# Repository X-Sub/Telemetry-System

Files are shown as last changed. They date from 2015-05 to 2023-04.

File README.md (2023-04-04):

# X-Sub Telemetry System
X-Sub Telemetry System is a project developed by the Mechatronics Research and Development Group (MRDG) at the Simon Bolivar University. The project aims to create a telemetry system for remote teleoperation of underwater robots and related technologies for research, exploration, and underwater inspection.

## Getting Started
To get started with this project, you need to fork your own copy of X-Sub/Telemetry-System. After forking, you can clone the project to your local machine and start working on it.

## Project Structure
The project is divided into different branches, and each branch contains code related to a specific module of the project. The branches include:

* LabView Visualizer
* MCU Firmware
* PCB
* Python Data Receiver-Transmitter
* Spectrum Analyzer

Additionally, there are other files included in the project such as a readme, gitignore, and gitattributes files.

## Usage
The X-Sub Telemetry System is designed to provide remote teleoperation of underwater robots. It consists of a 32-bit microcontroller that acquires sensor signals and centralizes them to a PC board. The PC board keeps a record of all data and forwards them to a base station, which commands for control motors and other actuators on board are received.

## Contributing
Contributions to this project are welcome. If you find any issues or want to make any improvements, you can create an issue or submit a pull request.

## License
This project is licensed under the MIT License - see the LICENSE.md file for details.

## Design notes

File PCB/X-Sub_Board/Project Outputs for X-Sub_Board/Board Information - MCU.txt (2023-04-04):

Board Information Report
Filename     : C:\Users\ddtdanilo\Dropbox\Tesis\X-Sub\PCB\X-Sub_Board\MCU.PcbDoc
Date         : 02/11/2015
Time         : 9:50:49
Time Elapsed : 00:00:00

General
    Board Size, 3664.37milsx2121.064mils
    Components on board, 36
count : 2

Routing Information
    Routing completion, 70,09%
    Connections, 107
    Connections routed, 75
    Connections remaining, 32
count : 4

Layer, Arcs, Pads, Vias, Tracks, Texts, Fills, Regions, ComponentBodies
    Top Layer, 0, 99, 0, 392, 0, 0, 0, 0
    Bottom Layer, 0, 0, 0, 141, 3, 0, 0, 0
    Mechanical 1, 0, 0, 0, 0, 0, 0, 0, 0
    Mechanical 2, 0, 0, 0, 0, 0, 0, 0, 0
    Mechanical 4, 0, 0, 0, 0, 0, 0, 0, 0
    Mechanical 13, 1, 0, 0, 64, 0, 0, 0, 16
    Mechanical 15, 0, 0, 0, 96, 0, 0, 0, 0
    Mechanical 16, 0, 0, 0, 50, 4, 0, 0, 0
    Multi-Layer, 0, 113, 14, 0, 0, 0, 1, 0
    Top Paste, 0, 0, 0, 0, 0, 0, 0, 0
    Top Overlay, 12, 0, 0, 132, 76, 1, 0, 0
    Top Solder, 0, 0, 0, 0, 0, 0, 0, 0
    Bottom Solder, 0, 0, 0, 0, 0, 0, 0, 0
    Bottom Overlay, 1, 0, 0, 4, 2, 0, 0, 0
    Bottom Paste, 0, 0, 0, 0, 0, 0, 0, 0
    Drill Guide, 0, 0, 0, 0, 0, 0, 0, 0
    Keep-Out Layer, 0, 0, 0, 0, 0, 0, 0, 0
    Drill Drawing, 0, 0, 0, 0, 0, 0, 0, 0
count : 18

Layer Pairs, Vias
    Top Layer - Bottom Layer, 14
count : 1

Non-Plated Hole Size, Pads, Vias
count : 0

Plated Hole Size, Pads, Vias
    0mils, 99, 0
    25mils, 0, 14
    35mils, 104, 0
    102.362mils, 2, 0
    126mils, 4, 0
    149.606mils, 3, 0
count : 6

Non-Plated Slot Size / Length, Pads
count : 0

Plated Slot Size / Length, Pads
count : 0

Non-Plated Square Hole Size, Pads
count : 0

Plated Square Hole Size, Pads
count : 0

Top Layer Annular Ring Size, Count
    -89.606mils, 3
    -42.362mils, 2
    0mils, 4
    25mils, 14
    35mils, 104
count : 5

Mid Layer Annular Ring Size, Count
    -89.606mils, 3
    -42.362mils, 2
    0mils, 4
    25mils, 14
    35mils, 104
count : 5

Bottom Layer Annular Ring Size, Count
    -89.606mils, 3
    -42.362mils, 2
    0mils, 4
    25mils, 14
    35mils, 104
count : 5

Pad Solder Mask, Count
    4mils, 212
count : 1

Pad Paste Mask, Count
    0mils, 212
count : 1

Pad Pwr/Gnd Expansion, Count
    20mils, 212
count : 1

Pad Relief Conductor Width, Count
    10mils, 212
count : 1

Pad Relief Air Gap, Count
    10mils, 212
count : 1

Pad Relief Entries, Count
    2, 212
count : 1

Via Solder Mask, Count
    4mils, 14
count : 1

Via Pwr/Gnd Expansion, Count
    20mils, 14
count : 1

Track Width, Count
    1.969mils, 8
    3.937mils, 152
    5mils, 16
    7.874mils, 122
    8mils, 15
    10mils, 72
    12mils, 356
    19.685mils, 97
    39.37mils, 41
count : 9

Arc Line Width, Count
    3.937mils, 1
    7.874mils, 8
    9.843mils, 4
    23.622mils, 1
count : 4

Arc Radius, Count
    4.921mils, 4
    11.811mils, 1
    19.685mils, 1
    78.74mils, 8
count : 4

Arc Degrees, Count
    122, 8
    360, 6
count : 2

Text Height, Count
    17mils, 2
    19.685mils, 4
    31mils, 2
    39.37mils, 52
    60mils, 20
    78.74mils, 1
    118.11mils, 4
count : 7

Text Width, Count
    2.55mils, 2
    8mils, 4
    10mils, 79
count : 3

Net Track Width, Count
    77780.886mils, 37
count : 1

Net Via Size, Count
    50mils, 37
count : 1

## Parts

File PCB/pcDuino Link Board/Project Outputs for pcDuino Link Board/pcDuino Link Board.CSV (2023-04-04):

Bill of Material for
On 30/09/2015 at 8:26:46
Comment | Pattern | Quantity | Components
Cap Pol1 | CAPR5-4X5 | 2 | C_5V, C_12V | Polarized Capacitor (Radial)
Header 10 | HDR1X10 | 1 | pcDuino Digital (8-13) | Header, 10-Pin
Header 2H | HDR1X2H | 1 | 5V_Sel | Header, 2-Pin, Right Angle
Header 2X2 | HDR2X2 | 2 | GPIO2, GPIO2_OUT | Header, 2-Pin, Dual row
Header 3 | HDR1X3 | 1 | Serial1 | Header, 3-Pin
Header 3X2 | HDR2X3 | 2 | GPIO1, ICSP | Header, 3-Pin, Dual row
Header 6 | HDR1X6 | 1 | pcDuinoADC | Header, 6-Pin
Header 8 | HDR1X8 | 2 | pcDuino Digital (0 - 7), pcDuino Power | Header, 8-Pin
LED1 | LED-1 | 3 | D_3.3, D_5, D_S | Typical RED GaAs LED
Res | RESC6332 | 3 | R_3.3, R_5, R_S | Resistor
Shield form compatible with the Arduino Uno R3. | UNO_R3_SHIELD | 1 | Duino Conn
Switching Power Source X-Sub | Fuente_Switching | 1 | PS
VCC_In | Vcc_In | 1 | Vin

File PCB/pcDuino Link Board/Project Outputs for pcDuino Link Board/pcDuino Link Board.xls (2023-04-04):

Comment | Description | Designator | Footprint | LibRef | Quantity
Header 2H | Header, 2-Pin, Right Angle | 5V_Sel | HDR1X2H | Header 2H | 1
Cap Pol1 | Polarized Capacitor (Radial) | C_5V, C_12V | CAPR5-4X5 | Cap Pol1 | 2
Shield form compatible with the Arduino Uno R3. |  | Duino Conn | UNO_R3_SHIELD | ARDUINO_R3_SHIELDNOLABELS | 1
LED1 | Typical RED GaAs LED | D_3.3, D_5, D_S | LED-1 | LED1 | 3
Header 3X2 | Header, 3-Pin, Dual row | GPIO1, ICSP | HDR2X3 | Header 3X2 | 2
Header 2X2 | Header, 2-Pin, Dual row | GPIO2, GPIO2_OUT | HDR2X2 | Header 2X2 | 2
Header 8 | Header, 8-Pin | pcDuino Digital (0 - 7), pcDuino Power | HDR1X8 | Header 8 | 2
Header 10 | Header, 10-Pin | pcDuino Digital (8-13) | HDR1X10 | Header 10 | 1
Header 6 | Header, 6-Pin | pcDuinoADC | HDR1X6 | Header 6 | 1
Switching Power Source X-Sub |  | PS | Fuente_Switching | Switching Power Source X-Sub | 1
Res | Resistor | R_3.3, R_5, R_S | RESC6332 | Res3 | 3
Header 3 | Header, 3-Pin | Serial1 | HDR1X3 | Header 3 | 1
VCC_In |  | Vin | Vcc_In | VCC_In | 1

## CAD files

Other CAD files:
MCU Firmware/test1/FLASH/Sources/main_c.obj
MCU Firmware/X-Sub MCU Firmware/FLASH/Sources/main_c.obj
MCU Firmware/test1/FLASH/Generated_Code/Cpu_c.obj
MCU Firmware/test1/FLASH/Project_Settings/Startup_Code/startcf_c.obj
MCU Firmware/test1/FLASH/Sources/Events_c.obj
MCU Firmware/X-Sub MCU Firmware/FLASH/Generated_Code/sMCU_OK_c.obj
MCU Firmware/X-Sub MCU Firmware/FLASH/Init_c.obj
MCU Firmware/X-Sub MCU Firmware/FLASH/Project_Settings/Startup_Code/startcf_c.obj
MCU Firmware/X-Sub MCU Firmware/FLASH/Sources/xSub_c.obj
MCU Firmware/test1/FLASH/Generated_Code/Vectors_c.obj
MCU Firmware/X-Sub MCU Firmware/FLASH/Generated_Code/RESET_INTERRUPT_c.obj
MCU Firmware/X-Sub MCU Firmware/FLASH/Sources/Events_c.obj
MCU Firmware/test1/FLASH/Generated_Code/IO_Map_c.obj
MCU Firmware/X-Sub MCU Firmware/FLASH/Generated_Code/M2_ESC_c.obj
MCU Firmware/X-Sub MCU Firmware/FLASH/Generated_Code/LedLight2_c.obj
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

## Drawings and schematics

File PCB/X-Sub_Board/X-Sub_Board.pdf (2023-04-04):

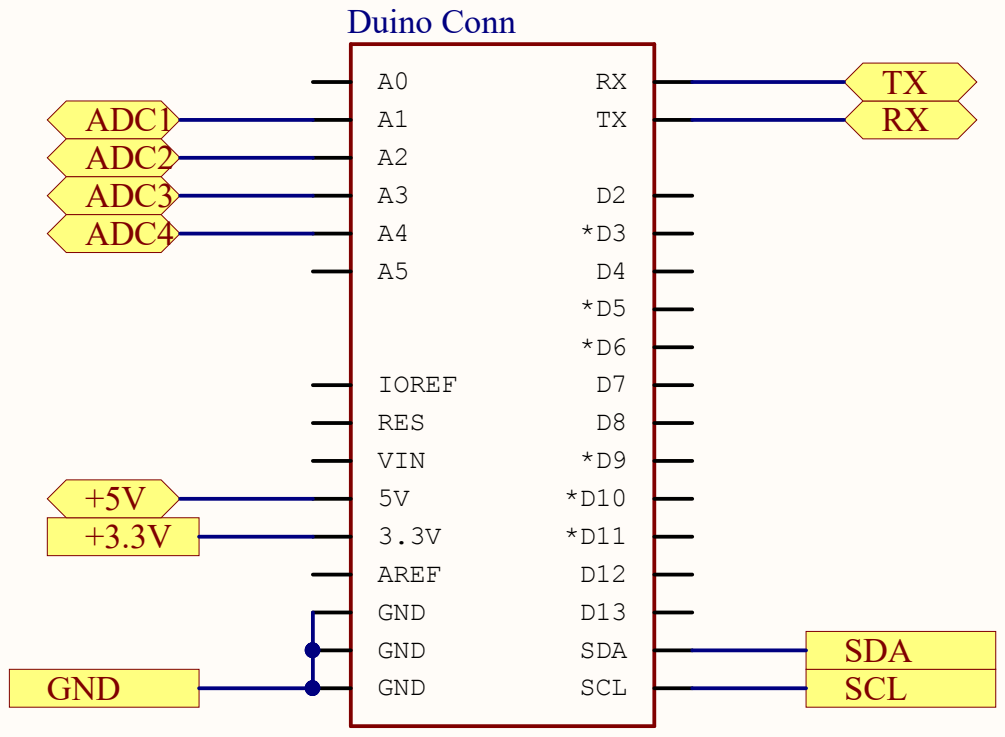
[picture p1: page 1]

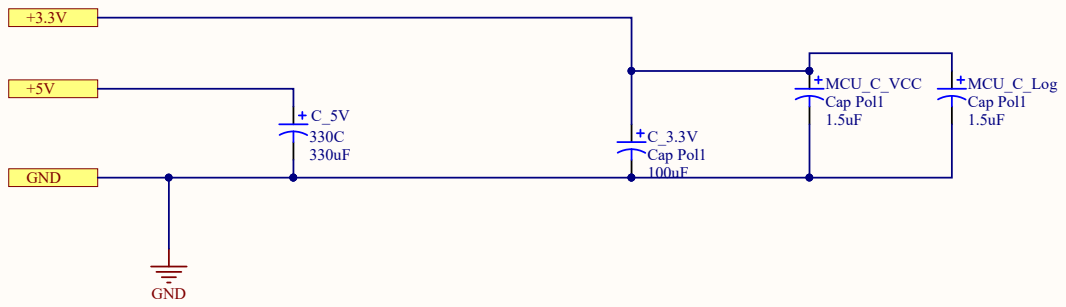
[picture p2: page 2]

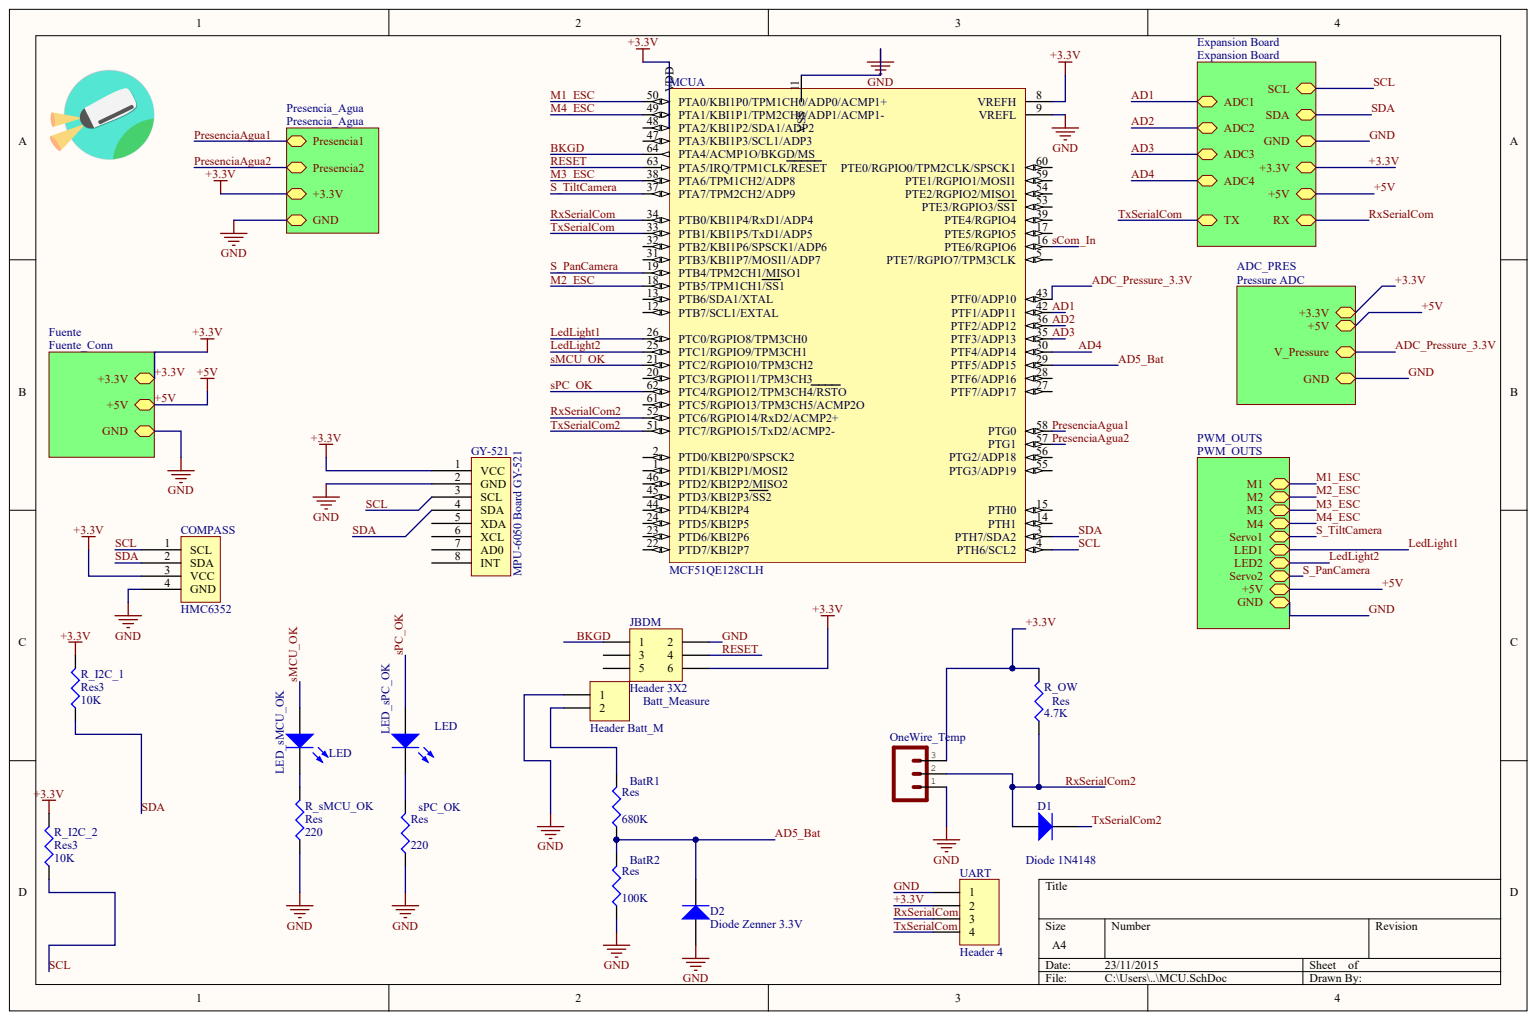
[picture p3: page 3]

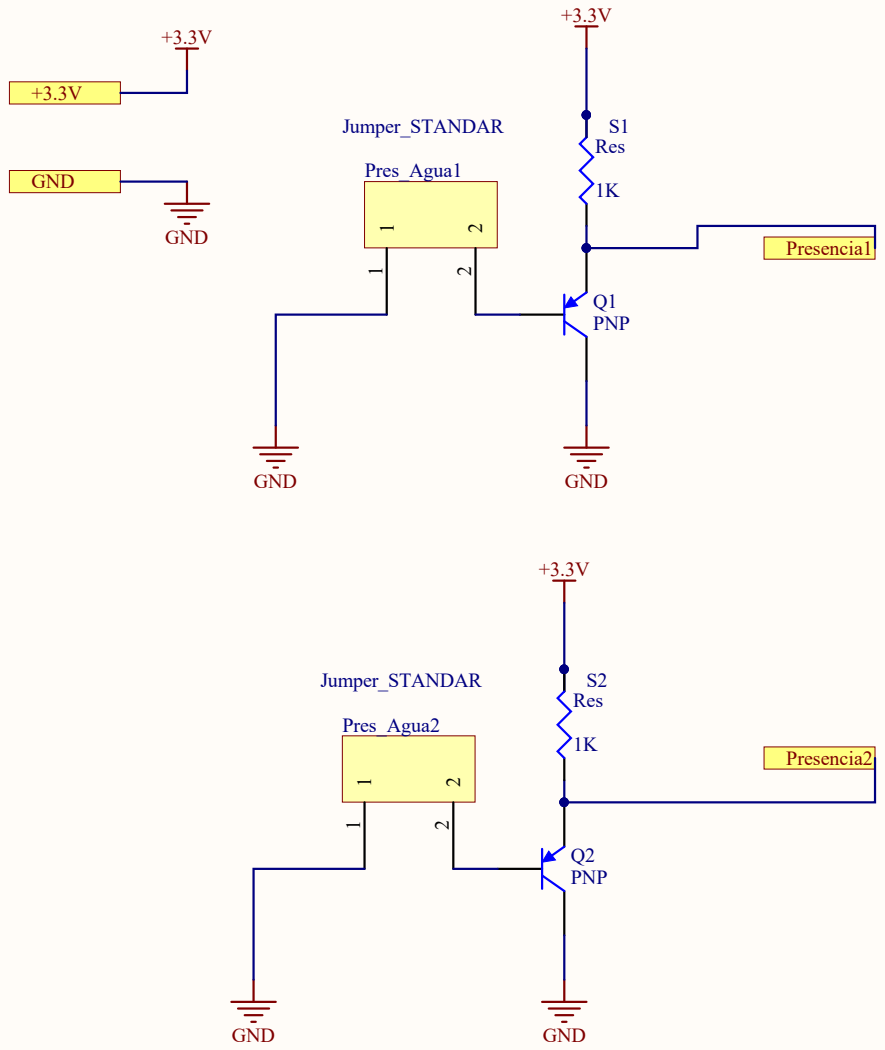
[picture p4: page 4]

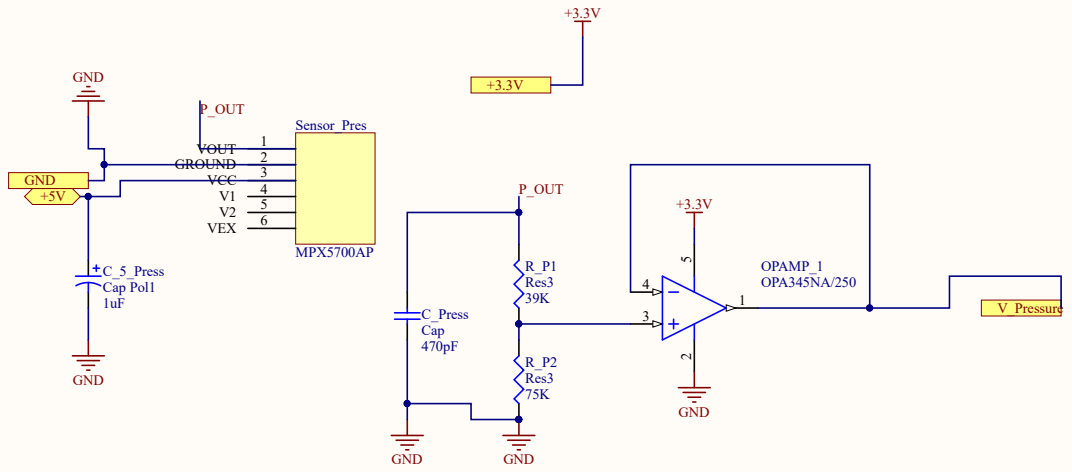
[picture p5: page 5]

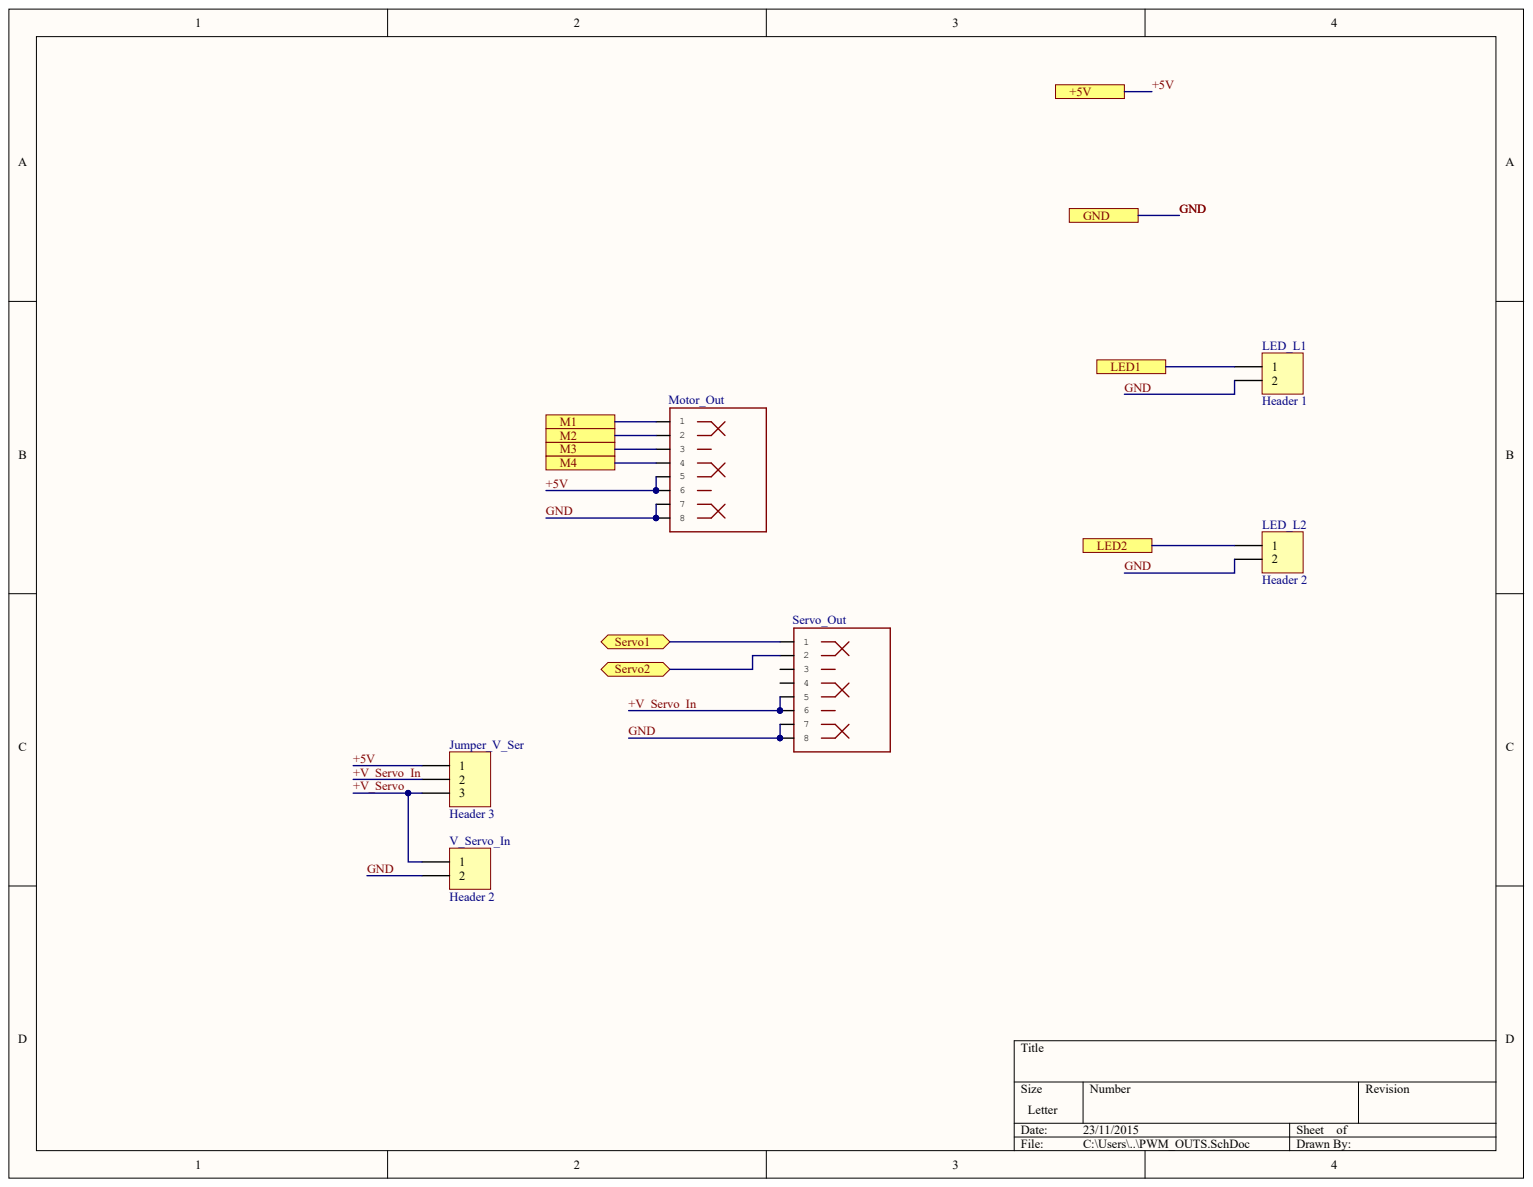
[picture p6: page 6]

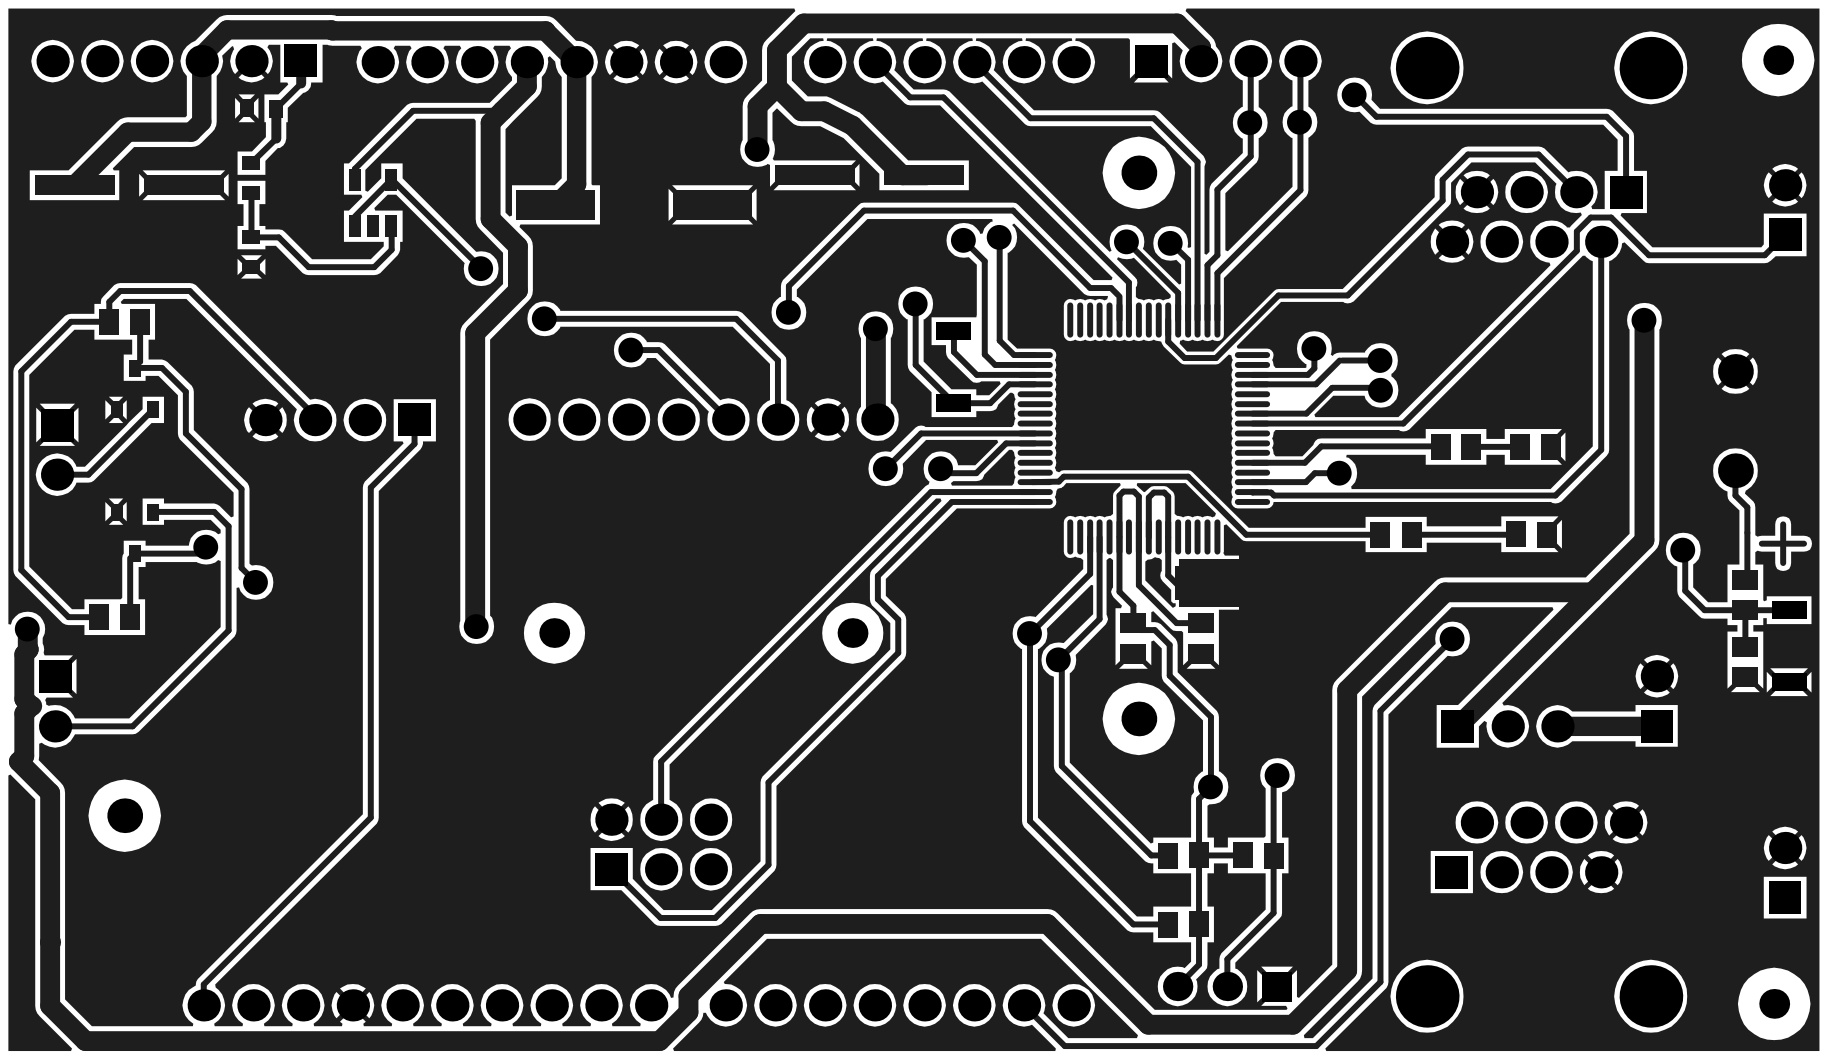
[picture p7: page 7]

# Board S

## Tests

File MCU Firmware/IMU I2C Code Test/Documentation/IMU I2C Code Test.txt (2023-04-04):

=============================================================================
List of generated methods in project: main

THIS TEXT DESCRIPTION IS GENERATED BY THE TOOL. DO NOT MODIFY IT.
=============================================================================

Module "CI2C1"     (component InternalI2C)
   - CI2C1_SendChar -When working as a MASTER, this method writes one (7-bit addressing) or two (10-bit addressing) slave 
                address bytes inclusive of R/W bit = 0 to the I2C bus and then writes one character (byte) to the bus. The 
                slave address must be specified before, by the "SelectSlave" or "SelectSlave10" method or in the component 
                initialization section, "Target slave address init" property. If interrupt service is enabled and the method 
                returns ERR_OK, it doesn't mean that transmission was successful. The state of transmission is obtainable from 
                (OnTransmitData, OnError or OnArbitLost) events.   When working as a SLAVE, this method writes a character to 
                the internal output slave buffer and, after the master starts the communication, to the I2C bus. If no 
                character is ready for a transmission (internal output slave buffer is empty), the Empty character will be sent 
                (see "Empty character" property).
   - CI2C1_RecvChar -When working as a MASTER, this method writes one (7-bit addressing) or two (10-bit addressing) slave 
                address bytes inclusive of R/W bit = 1 to the I2C bus, then reads one character (byte) from the bus and then 
                sends the stop condition. The slave address must be specified before, by the "SelectSlave" or "SelectSlave10" 
                method or in component initialization section, property "Target slave address init". If interrupt service is 
                enabled and the method returns ERR_OK, it doesn't mean that transmission was finished successfully. The state 
                of transmission must be tested by means of events (OnReceiveData, OnError or OnArbitLost). In case of 
                successful transmission, received data is ready after OnReceiveData event is called.   When working as a SLAVE, 
                this method reads a character from the input slave buffer.
   - CI2C1_SendBlock -When working as a MASTER, this method writes one (7-bit addressing) or two (10-bit addressing) slave 
                address bytes inclusive of R/W bit = 0 to the I2C bus and then writes the block of characters to the bus. The 
                slave address must be specified before, by the "SelectSlave" or "SlaveSelect10" method or in component 
                initialization section, "Target slave address init" property. If interrupt service is enabled and the method 
                returns ERR_OK, it doesn't mean that transmission was successful. The state of transmission is detectable by 
                means of events (OnTransmitData, OnError or OnArbitLost). Data to be send is not copied to an internal buffer 
                and remains in the original location. Therefore the content of the buffer should not be changed until the 
                transmission is complete. Event OnTransmitData can be used to detect the end of the transmission.  When working 
                as a SLAVE, this method writes a block of characters to the internal output slave buffer and then, after the 
                master starts the communication, to the I2C bus. If no character is ready for a transmission (internal output 
                slave buffer is empty), the "Empty character" will be sent (see "Empty character" property). In SLAVE mode the 
                data are copied to an internal buffer, if specified by "Output buffer size" property.
   - CI2C1_RecvBlock -When working as a MASTER, this method writes one (7-bit addressing) or two (10-bit addressing) slave 
                address bytes inclusive of R/W bit = 1 to the I2C bus, then reads the block of characters from the bus and then 
                sends the stop condition. The slave address must be specified before, by the "SelectSlave" or "SelectSlave10" 
                method or in component initialization section, "Target slave address init" property. If interrupt service is 
                enabled and the method returns ERR_OK, it doesn't mean that transmission was finished successfully. The state 
                of transmission must be tested by means of events (OnReceiveData, OnError or OnArbitLost). In case of 
                successful transmission, received data is ready after OnReceiveData event is called.   When working as a SLAVE, 
                this method reads a block of characters from the input slave buffer.
   - CI2C1_GetCharsInTxBuf -Returns number of characters in the output buffer. In SLAVE mode returns the number of characters 
                in the internal slave output buffer. In MASTER mode returns number of characters to be sent from the user 
                buffer (passed by SendBlock method).  This method is not supported in polling mode.
   - CI2C1_GetCharsInRxBuf -Returns number of characters in the input buffer. In SLAVE mode returns the number of characters in 
                the internal slave input buffer. In MASTER mode returns number of characters to be received into a user buffer 
                (passed by RecvChar or RecvBlock method).   This method is not supported in polling mode.
   - CI2C1_SelectSlave -This method selects a new slave for communication by its 7-bit slave address value. Any send or receive 
                method directs to or from selected device, until a new slave device is selected by this method. This method is 
                not available for the SLAVE mode.

Module "Cpu"       (component MCF51QE128_80)
   - Cpu_EnableInt -Enables maskable interrupts
   - Cpu_DisableInt -Disables maskable interrupts

===================================================================================

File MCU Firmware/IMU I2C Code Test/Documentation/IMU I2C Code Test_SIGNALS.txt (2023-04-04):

=================================================================
THIS FILE WAS GENERATED BY "Processor Expert version 10.3 for Freescale Microcontrollers".
Project "IMU I2C Code Test", 2015-07-17, 19:45, # CodeGen: 1
DO NOT MODIFY IT.
-----------------------------------------------------------------
There is no signal defined in this project.
 Hint: Signals may be defined in the Inspector (advanced or expert view)
=================================================================

=================================================================
 SIGNAL LIST
-----------------------------------------------------------------
SIGNAL-NAME [DIR]        => PIN-NAME [PIN-NUMBER]
-----------------------------------------------------------------
=================================================================

=================================================================
 PIN LIST
-----------------------------------------------------------------
PIN-NAME [PIN-NUM]       => SIGNAL-NAME [DIRECTION]
-----------------------------------------------------------------
=================================================================

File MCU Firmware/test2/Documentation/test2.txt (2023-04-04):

=============================================================================
List of generated methods in project: main

THIS TEXT DESCRIPTION IS GENERATED BY THE TOOL. DO NOT MODIFY IT.
=============================================================================

Module "UTIL1"     (component Utility)
   - UTIL1_strcpy -Same as normal strcpy, but safe as it does not write beyond the buffer.
   - UTIL1_strcat -Same as normal strcat, but safe as it does not write beyond the buffer.
   - UTIL1_chcat -Adds a single character to a zero byte terminated buffer. It cares about buffer overflow.
   - UTIL1_Num8sToStr -Converts a signed 8bit value into a string.
   - UTIL1_Num8uToStr -Converts an unsigned 8bit value into a string.
   - UTIL1_Num16sToStr -Converts a signed 16bit value into a string.
   - UTIL1_Num16uToStr -Converts a signed 16bit value into a string.
   - UTIL1_Num32uToStr -Converts an unsigned 32bit value into a string.
   - UTIL1_Num32sToStr -Converts a signed 32bit value into a string.
   - UTIL1_Num16sToStrFormatted -Converts a 16bit signed value to string.
   - UTIL1_Num16uToStrFormatted -Converts a 16bit unsigned value to string.
   - UTIL1_Num32uToStrFormatted -Converts a 32bit unsigned value to string.
   - UTIL1_Num32sToStrFormatted -Converts a 32bit signed value to string.
   - UTIL1_strcatNum8u -Appends a 8bit unsigned value to a string buffer.
   - UTIL1_strcatNum8s -Appends a 8bit signed value to a string buffer.
   - UTIL1_strcatNum16u -Appends a 16bit unsigned value to a string buffer.
   - UTIL1_strcatNum16s -Appends a 16bit signed value to a string buffer.
   - UTIL1_strcatNum32u -Appends a 32bit signed value to a string buffer.
   - UTIL1_strcatNum32s -Appends a 32bit signed value to a string buffer.
   - UTIL1_strcatNum16uFormatted -Appends a 16bit unsigned value to a string buffer in a formatted way.
   - UTIL1_strcatNum16sFormatted -Appends a 16bit signed value to a string buffer in a formatted way.
   - UTIL1_strcatNum32uFormatted -Appends a 32bit unsigned value to a string buffer in a formatted way.
   - UTIL1_strcatNum32sFormatted -Appends a 32bit signed value to a string buffer in a formatted way.
   - UTIL1_strcatNum8Hex -Appends a 8bit unsigned value to a buffer as hex number (without a 0x prefix).
   - UTIL1_strcatNum16Hex -Appends a 16bit unsigned value to a buffer as hex number (without a 0x prefix).
   - UTIL1_strcatNum24Hex -Appends a 32bit unsigned value to a buffer as hex number (without a 0x prefix). Only 24bits are used.
   - UTIL1_strcatNum32Hex -Appends a 16bit unsigned value to a buffer as hex number (without a 0x prefix).
   - UTIL1_strcatNum32sDotValue100 -Appends a 32bit signed value to a buffer. The value is in 1/100 units.  For example for the 
                value -13456 it will append the string "-134.56"
   - UTIL1_IsLeapYear -Returns true if a given year is a leap year
   - UTIL1_WeekDay -Returns the weekday for a given date >= 1.Jan.1900
   - UTIL1_ReadEscapedName -Scans an escaped name from a string. This is useful e.g. for double quoted file names.
   - UTIL1_xatoi -Custom atoi() (ascii to int) implementation by Elm Chan
   - UTIL1_ScanDate -Scans a date in the format "dd.mm.yyyy" or "dd-mm-yyyy". For yy it will expand it to 20yy.
   - UTIL1_ScanTime -Scans a time string in the format "hh:mm:ss,hh" with the part for the ",hh" is optional.
   - UTIL1_ScanDecimal8uNumber -Scans a decimal 8bit unsigned number
   - UTIL1_ScanDecimal8sNumber -Scans a decimal 8bit signed number
   - UTIL1_ScanDecimal16uNumber -Scans a decimal 16bit unsigned number
   - UTIL1_ScanDecimal16sNumber -Scans a decimal 16bit signed number
   - UTIL1_ScanDecimal32uNumber -Scans a decimal 32bit unsigned number
   - UTIL1_ScanDecimal32sNumber -Scans a decimal 32bit signed number
   - UTIL1_ScanDecimal32sDotNumber -Scans a decimal 32bit signed number with a following dot (fractional part), e.g. "-34587.
                0248", it will return the (signed) integral and fractional part with number of fractional zeros. The function 
                accepts as well numbers  like "17" (no fractional part" or "17.0"
   - UTIL1_ScanHex8uNumber -Scans a hexadecimal 8bit number, starting with 0x
   - UTIL1_ScanHex8uNumberNoPrefix -Scans a hexadecimal 8bit number, without 0x
   - UTIL1_ScanHex16uNumber -Scans a hexadecimal 16bit number, starting with 0x
   - UTIL1_ScanHex32uNumber -Scans a hexadecimal 32bit number, starting with 0x
   - UTIL1_ScanSeparatedNumbers -Scans multiple numbers separated by character, e.g. "123.68.5.3"
   - UTIL1_ScanDoubleQuotedString -Scans a string inside double quotes and returns it without the double quotes.
   - UTIL1_strcmp -Wrapper to the standard strcmp() routine
   - UTIL1_strncmp -Wrapper to the standard strncmp() routine
   - UTIL1_strFind -Searches a substring inside a string and returns the position.
   - UTIL1_strtailcmp -Compares the tail of a string and returns 0 if it matches, 1 otherwise
   - UTIL1_strlen -Wrapper to the standard strlen() function.
   - UTIL1_strCutTail -Removes a tailing substring from a string. The string passed will be modified (the tail is cut by 
                writing a zero byte to the string!)

Module "TEMP1"     (component LM61B)
   - TEMP1_Measure -Starts the measuring process for the sensor value.
   - TEMP1_ReadTemperature -Reads the temperature from the sensor.

Module "AD1"       (component ADC)
   - AD1_Measure -This method performs one measurement on all channels that are set in the component inspector. (Note: If the 
                <number of conversions> is more than one the conversion of A/D channels is performed specified number of times.)
   - AD1_MeasureChan -This method performs measurement on one channel. (Note: If the <number of conversions> is more than one 
                the conversion of the A/D channel is performed specified number of times.)
   - AD1_GetChanValue -Returns the last measured value of the required channel. Format and width of the value is a native 
                format of the A/D converter.
   - AD1_GetValue8 -This method returns the last measured values of all channels. Compared with <GetValue> method this method 
                returns more accurate result if the <number of conversions> is greater than 1 and <AD resolution> is less than 
                8 bits. In addition, the user code dependency on <AD resolution> is eliminated.
   - AD1_GetChanValue8 -This method returns the last measured value of the required channel. Compared with <GetChanValue> 
                method this method returns more accurate result if the <number of conversions> is greater than 1 and <AD 
                resolution> is less than 8 bits. In addition, the user code dependency on <AD resolution> is eliminated.
   - AD1_GetValue16 -This method returns the last measured values of all channels. Compared with <GetValue> method this method 
                returns more accurate result if the <number of conversions> is greater than 1 and <AD resolution> is less than 
                16 bits. In addition, the user code dependency on <AD resolution> is eliminated.
   - AD1_GetChanValue16 -This method returns the last measured value of the required channel. Compared with <GetChanValue> 
                method this method returns more accurate result if the <number of conversions> is greater than 1 and <AD 
                resolution> is less than 16 bits. In addition, the user code dependency on <AD resolution> is eliminated.

Module "Cpu"       (component MCF51QE128_80)
   - Cpu_EnableInt -Enables maskable interrupts
   - Cpu_DisableInt -Disables maskable interrupts

===================================================================================

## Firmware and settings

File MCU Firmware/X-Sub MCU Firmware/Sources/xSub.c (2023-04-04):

/*
 * xSub.c
 *
 *  Created on: Jun 11, 2015
 *      Author: ddtdanilo
 */

/*Includes*/
#include "Cpu.h"
#include "Events.h"
#include "M1_ESC.h"
#include "M2_ESC.h"
#include "M3_ESC.h"
#include "M4_ESC.h"
/* Include shared modules, which are used for whole project */
#include "PE_Types.h"
#include "PE_Error.h"
#include "PE_Const.h"
#include "IO_Map.h"

/*Mis includes*/
#include "xSub.h"
#include "OneWire.h"




//Cambia el Status de un LED
//Hace que se mantenga encendido o titilando si està activo.
void lStatus(byte nLed, bool status)
{
	switch(nLed)
	{
		case 0x00:
			led0x00 = status;
			break;
			
		case 0x01:
			led0x01 = status;		
			break;
			
		case 0x02:
			led0x02 = status;				
			break;
		
		case 0x03:
			led0x03 = status;				
			break;
			
		case 0x04:
			led0x04 = status;				
			break;
		
		case 0x05:
			led0x05 = status;		
			break;
					
		case 0x06:
			led0x06 = status;				
			break;
			
		case 0x07:
			led0x07 = status;						
			break;
				
	}
}

//Activa a sMCU_OK
void sMCU_OK_W()
{
	lStatus(0x00,TRUE);
}

//Desactiva a sMCU_OK
void sMCU_OK_NW()
{
	lStatus(0x00,FALSE);
}

//Muestra titilando a sPC_OK
void sCom_In_W()
{
	lStatus(0x01,TRUE);
}

//Muestra titilando a sPC_OK
void sCom_In_NW()
{
	lStatus(0x01,FALSE);
}

//Muestra titilando a sPC_OK
void sPC_OK_W()
{
	lStatus(0x02,TRUE);
}

//Muestra titilando a sPC_OK
void sPC_OK_NW()
{
	lStatus(0x02,FALSE);
}

//paraliza el MCU por el tiempo time en ms
void delay(word time)
{
	//sPC_OK_W();
	Cpu_Delay100US(time*10);
}


//Inicializa los motores
void initMxSub(byte tipo){
	if(tipo == 1)//HK 30A
	{
	word spDC;
	M1_ESC_Enable();
	M2_ESC_Enable();
	M3_ESC_Enable();
	M4_ESC_Enable();
	spDC = CENTERDC; //0xED71 = 7.24% = 60788
	M1_ESC_SetRatio16(spDC);
	M2_ESC_SetRatio16(spDC);
	M3_ESC_SetRatio16(spDC);
	M4_ESC_SetRatio16(spDC);
	delay(5000);
	}
	
	if(tipo == 2)//Skywing
		{
		word spDC;
		M1_ESC_Enable();
		M2_ESC_Enable();
		M3_ESC_Enable();
		M4_ESC_Enable();
		spDC = MAXFORWARD;
		M1_ESC_SetRatio16(spDC);
		M2_ESC_SetRatio16(spDC);
		M3_ESC_SetRatio16(spDC);
		M4_ESC_SetRatio16(spDC);
		delay(5000);
		}
	

}

//Coloca un DC a todos los motores
void setDC(word Speed)
{
 (void)M1_ESC_SetRatio16(Speed);
 (void)M2_ESC_SetRatio16(Speed);
 (void)M3_ESC_SetRatio16(Speed);
 (void)M4_ESC_SetRatio16(Speed);
}

//Setea la velocidad de los motores de manera individual. Rango de 10 bits-> 0 - 1023
void setMotorSpeed1024(word Speed,byte Motor){
	
	Speed = map(Speed,0,1023,MAXFORWARD,MAXBACKWARD);
	
	switch(Motor){
	
	case 1:
		    (void)M1_ESC_SetRatio16(CENTERDC);
			(void)M1_ESC_SetRatio16(Speed);
	case 2:
		    (void)M2_ESC_SetRatio16(CENTERDC);
			(void)M2_ESC_SetRatio16(Speed);
	case 3:
		    (void)M3_ESC_SetRatio16(CENTERDC);
			(void)M3_ESC_SetRatio16(Speed);
	case 4:
		    (void)M4_ESC_SetRatio16(CENTERDC);
			(void)M4_ESC_SetRatio16(Speed);	
	}
}

//Setea la velocidad de los motores de manera individual. Rango de 8 bits-> 0 - 255
void setMotorSpeed256(byte Speed,byte Motor){
	
	Speed = map(Speed,0,255,MAXFORWARD,MAXBACKWARD);
	
	switch(Motor){
	
	case 1:
		    (void)M1_ESC_SetRatio8(CENTERDC);
			(void)M1_ESC_SetRatio8(Speed);
	case 2:
		    (void)M2_ESC_SetRatio8(CENTERDC);
			(void)M2_ESC_SetRatio8(Speed);
	case 3:
		    (void)M3_ESC_SetRatio8(CENTERDC);
			(void)M3_ESC_SetRatio8(Speed);
	case 4:
		    (void)M4_ESC_SetRatio8(CENTERDC);
			(void)M4_ESC_SetRatio8(Speed);	
	}
}

//Setea la velocidad de los motores de manera individual. Rango de 10 bits-> 0 - 1023 SKYWING
void setMotorSpeed1024SW(word Speed,byte Motor){
	
	Speed = map(Speed,0,1023,MAXBACKWARD,CENTERDC);
	
	switch(Motor){
	
	case 1:
		    
			(void)M1_ESC_SetRatio16(Speed);
	case 2:
		    
			(void)M2_ESC_SetRatio16(Speed);
	case 3:
		    
			(void)M3_ESC_SetRatio16(Speed);
	case 4:
		    
			(void)M4_ESC_SetRatio16(Speed);	
	}
}
//SERVOS

  /*Pan*/
void servoPanAngle(word Angle)//Resolución de 0 - 255
{
	Angle = map(Angle,0,255,MINSERVOUS,MAXSERVOUS);
	S_PanCamera_SetDutyUS(Angle);
}

void servoPan1024(word In)//Resolución de 0 - 1023 (0 - 0x1023)
{
	In = map(In,0,1023,MINSERVOUS,MAXSERVOUS);
	S_PanCamera_SetDutyUS(In);
}

   /*Tilt*/
void servoTiltAngle(word Angle)//Resolución de 0 - 255
{
	Angle = map(Angle,0,255,MINSERVOUS,MAXSERVOUS);
	S_TiltCamera_SetDutyUS(Angle);
}

void servoTilt1024(word In)//Resolución de 0 - 1023 (0 - 0x1023)
{
	In = map(In,0,1023,MINSERVOUS,MAXSERVOUS);
	S_TiltCamera_SetDutyUS(In);
}

/****LEDS****/
 void setLEDPWM(word PWM){
	 LedLight1_SetRatio16(PWM);
	 LedLight2_SetRatio16(PWM);
 }
 
 void setLED1PWM(word PWM){
	 LedLight1_SetRatio16(PWM);
 }
 
 void setLED2PWM(word PWM){
	 LedLight2_SetRatio16(PWM);
 }


//MAPEA
long map(long x, long in_min,long in_max,long out_min, long out_max){
	return (x-in_min)*(out_max-out_min)/(in_max-in_min)+out_min;
}


/*I2C*/

byte writeRegisterI2C(byte reg, byte data)//manera sencilla de editar un registro
{
	byte DATA[2];
	word Sent;
	byte err;
	DATA[0] = reg; // registro a editar
	DATA[1] = data; // data a enviar
	err = I2C_SendBlock(DATA,2,&Sent);
	return err;
}

void initMPU()//Inicializa la IMU
{
	byte err;
	byte reg = 0x6B; // PWR_MGMT_1 register
	byte data = 0x00; // set to zero (wakes up the MPU-6050)
	(void)I2C_SelectSlave(MPU);
	while(writeRegisterI2C(reg,data) != ERR_OK);
	delay(10);
	while(writeRegisterI2C(MPU6050_ACCEL_CONFIG,MPU6050_AFS_SEL_4G) != ERR_OK);//+-4G
	while(writeRegisterI2C(MPU6050_GYRO_CONFIG,MPU6050_FS_SEL_1000) != ERR_OK);//+-1000º/s
}


//Obtener data de la IMU. data debe ser de tamaño 14
void dataMPUtoArray(byte dataIn[])
{
	word Sent;
	(void)I2C_SelectSlave(MPU);
	while(I2C_SendChar(0x3B) != ERR_OK);
	while(I2C_RecvBlock(dataIn,14,&Sent) != ERR_OK);
	
	aceleracionX.HIGH.data = dataIn[0];
	aceleracionX.LOW.data = dataIn[1];
	aceleracionY.HIGH.data = dataIn[2];
	aceleracionY.LOW.data = dataIn[3];
	aceleracionZ.HIGH.data = dataIn[4];
	aceleracionZ.LOW.data = dataIn[5];
	tempInterna.HIGH.data = dataIn[6];
	tempInterna.LOW.data = dataIn[7];
	velAngularX.HIGH.data = dataIn[8];
	velAngularX.LOW.data = dataIn[9];
	velAngularY.HIGH.data = dataIn[10];
	velAngularY.LOW.data = dataIn[11];
	velAngularZ.HIGH.data = dataIn[12];
	velAngularZ.LOW.data = dataIn[13];
		/*
		 * 
		  AcXH = Wire.read();
		  AcXL = Wire.read();

		  AcYH = Wire.read();
		  AcYL = Wire.read();

		  AcZH = Wire.read();
		  AcZL = Wire.read();

		  // 0x41 (TEMP_OUT_H) & 0x42 (TEMP_OUT_L)
		  TmpH = Wire.read();
		  TmpL = Wire.read();


		  GyXH = Wire.read();
		  GyXL = Wire.read();
		  GyYH = Wire.read();
		  GyYL = Wire.read();
		  GyZH = Wire.read();
		  GyZL = Wire.read();
		*/
}
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

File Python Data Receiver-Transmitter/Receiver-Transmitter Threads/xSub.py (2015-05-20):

import threading
import serial
import logging
import time
import datetime
from pynmea import nmea


PuertoS_xSub = 'COM7'
PuertoS_GPS = 'COM3' #GPS

def info():
	infoProyecto = u"El X-Sub es un proyecto del Grupo de Investigacion y Desarrollo en Mecatronica"
	print(infoProyecto)

version = '0.1'


def logInit(ruta):
	logging.basicConfig(filename='C:/dataLog_test/datalog.txt',level=logging.DEBUG)
	Head = datetime.datetime.now().strftime(" Fecha: %d/%m/%Y Hora: %H:%M:%S")
	logging.info(Head)




##THREADS
class Threads():

	statusOK = False

	def startThreads(self):
		#Inicialización de los Threads
		statusOK = True
		self.Servidor.start()
		self.Serial.start()
		self.DataLogger.start()
		



	def xSub_Servidor():
		'''Este Thread se encarga de la comunicacion por tcp/ip para transmisión de datos'''
		print("threading.currentThread().getName()")
		while True:
			print("HOLA")
		




	def xSub_Serial():
		"""Este Thread se encarga de la comunicacion por Serial para transmisión de datos"""
		#print(threading.currentThread().getName())
		#ser1 = serial.Serial('COM7',115200)
		##x = ser.read()          # read one byte
		#s = ser.read(3)        # read up to ten bytes (timeout)
		#print(s)
	#
		#ser.close()
		try:
			ser = serial.Serial(xSub.PuertoS_GPS,57600)
			while True:
				# read what is on serial port
				data = ser.readline().decode("ASCII")
				#data = '$GPGGA,180914.600,1024.6583,N,06652.9368,W,2,6,1.09,1201.0,M,-18.1,M,0000,0000*5B\r\n'
				#print(data)
				#reads bytes followed by a newline
				if data[0:6] == '$GPGGA':
					#print(data)      #print the sentence to the console
					gpgga = nmea.GPGGA()  # class constructor
					gpgga.parse(data)   # method for parsing the sentence
					lats = gpgga.latitude
					lat_dir = gpgga.lat_direction
					longs = gpgga.longitude
					long_dir = gpgga.lon_direction
					time = gpgga.timestamp
					alt = gpgga.antenna_altitude
					print(time + '\n')
					Hora = 'Hora UTC:' + time[0:2] + ':' + time[2:4] + ':' + time[4:6]
					print(Hora)
					logging.info(Hora)
					time.sleep(1) 
		except:
			print("Problema de Puerto Serial")
			

	def xSub_DataLogger():
		"""Este Thread se encarga de la creación de un archivo .txt con la data recibida"""
		print("xSub_Datalogger")
		return



	#Creación de Threads
	Servidor = threading.Thread(name='tServidor', target = xSub_Servidor)
	Serial = threading.Thread(name='tSerial', target = xSub_Serial)
	DataLogger = threading.Thread(name='tDataLogger', target = xSub_DataLogger)

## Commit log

2015-02-13 Creación de Repositorio
2015-03-16 Creación de Proyecto en Altium
    [X-Sub_Board.PrjPcb]
2015-04-14 Inicialización de Threads y Console Log
    Inicialización de Threads y Console Log
2015-04-15 Inicialización de Proyecto en Simulink
2015-04-15 Obtención de datos basada en el ejemplo de Arduino
    Fuente:
    http://playground.arduino.cc/Main/MPU-6050?action=sourceblock&num=1
2015-04-15 Envío de Trama Auxiliar, Sólo AccelY, H y L
2015-04-18 Test de transmisión
2015-04-18 Adquisición de Temperatura funcionando
2015-04-18 Funcionamiento de Analizador de espectro
    El delay(20) implica un muestreo cada 20 ms, lo que implica que en
    simulink debe estar este parámetro igual.
2015-04-19 Funcionando con ajuste de aceleración.
    El sensor muestra +-2g, a una resolución de 16 bits. ((2^16)/4)*Data_In
    = n*g
2015-04-19 Configuración para rango de aceleración +-4G
2015-04-19 Mejora de organizacion en simulink y 1000º/s de gyro
2015-04-22 Inclusión de Lectura de Datos del GPS por Serial
2015-04-22 Establece la hora en el logging cada segundo
2015-04-28 Cambio de test
2015-05-20 Funcionamiento por Threads
2015-05-30 Creación de workspace de CodeWarrior
2015-05-30 Creación de Proyecto en CW
2015-06-11 Motor Init
2015-06-12 MCU Working OK
    Status OK. First LED
    [Cpu_c.obj, Events_c.obj, IO_Map_c.obj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]
2015-06-15 Working Status Leds with blink
    [Aux_Int_c.obj, Cpu_c.obj, Events_c.obj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]
2015-07-10 Potenciometro a PWM
    [ADC_c.obj, Aux_Int_c.obj, Cpu_c.obj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]
2015-07-10 Motor Working. Avanza y retrocede
    [main_c.obj, xSub_c.obj]
2015-07-10 Variables globales
    [Init_c.obj, main_c.obj, xSub_c.obj]
2015-07-10 setMotorSpeed funciona. Rango de 0-1023
    setMotorSpeed funciona. Rango de 0-1023, El centro es 511. (0 RPM)
    [ADC_c.obj, Aux_Int_c.obj, Cpu_c.obj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]
2015-07-12 Servo Working
    Added servoXXAngle (0-179) and servoXX1024. from 900 to 3300 us tOn
    [ADC_c.obj, main_c.obj]
2015-07-12 Some bugs & Fixes. Tilt Working Servo
    [Cpu_c.obj, Events_c.obj, main_c.obj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]
2015-07-12 Agregada funciones de LEDS
    resolucion de 16 bits (2 Bytes)
    [ADC_c.obj, Aux_Int_c.obj, Cpu_c.obj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]
2015-07-15 Serial Test
    [Events_c.obj, Init_c.obj, main_c.obj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]
2023-04-04 16 bit protocol working
    I2C Working
    I2C working with MatLab Spectrum Analyser
    Compass HMC63852 Working :dango: orking :D
    Test
    Esquemático
    1ra Versión del esquemático
    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
    [001.SchLib, ADC_c.obj, Aux_Int_c.obj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]
2023-04-04 Fuente y Trazos principales
    PCB
    make pull request
    3rd version
    4rd Version with GND PLANES
    Rx & Tx fix y Inicio de shield con las medidas
    1ra version de tarjeta link
    Cambio de formato de resistencias a 0603 y 0805
    With minimelf and battery meas. Sin pistas
    Adaptador pcDuino con las correcciones
    Segunda Version OK
    [001.SchLib, Expansion Board.SchDoc, Expansion_In.SchDoc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]
2023-04-04 3ra Version, lista para Fabricar
    Versión de PCB Fabricada
    Versión de PCB Fabricada en el Lab C.
    Rec y Env OK
    Update README.txt
    Descripción en Español e Inglés**
    Libro de tesis
    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
    [Events_c.obj, Fuente_Conn.SchDoc, MCU.PcbDoc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]
2026-07-25 feat!: modernize the X-Sub research archive (#3)
    Document and curate the historical system, add maintained protocol tools and tests, establish repository governance and CI, and remove generated workspace artifacts from the current branch.
